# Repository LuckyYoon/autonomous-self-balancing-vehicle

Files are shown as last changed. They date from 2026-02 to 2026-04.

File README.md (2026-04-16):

# Autonomous Self-Balancing Vehicle

This project explores the design and implementation of an autonomous, self-balancing bicycle using a reaction wheel for stabilization. The system combines embedded control, power electronics, and robotic autonomy to achieve balance, perception, and navigation on a dynamically unstable platform.

A reaction wheel driven by a high-speed motor provides roll stabilization, while steering, drive, and braking actuators enable controlled motion. Low-level balancing is handled by an embedded controller, with higher-level perception and autonomy running on an onboard computer using ROS2.

The autonomy stack integrates stereo vision, LiDAR, and inertial sensing to perform visual SLAM, localization, and obstacle-aware navigation. The project emphasizes tight integration between mechanical design, real-time control, and perception-driven decision making.

This repository contains the hardware designs, embedded firmware, autonomy software, and documentation developed in the course of building and testing the system.

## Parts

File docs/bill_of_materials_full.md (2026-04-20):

# Bill of Materials - Full Configuration

| Category | Item | Qty | Notes | Unit Cost | Total Cost |
|---|---|---:|---|---:|---:|
| Bike | [Harper Fixie Bike](https://retrospec.com/products/harper-fixie-bike-single-speed-legacy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) | 1 | This fixed gear bike has a tubular frame making it easier to design mounts. It also reduces any unnecessary parts, for a lightweight bicycle that is easier to balance. | $219.99 | $219.99 |
| Active Reaction Wheel | [Low-Carbon Steel Disc 6" Diameter, 1" Long](https://www.mcmaster.com/7786T74/) | 1 | Steel disk stock for the active reaction wheel. It is 1" thick (motor shaft is 0.787" long), and has a 6" diameter which give us a good weight and inertia for the wheel. | $33.62 | $33.62 |
| Active Reaction Wheel | [ODESC V4.2 24V Single-Drive FOC BLDC Motor Controller](https://www.amazon.com/FLIPSKY-Single-Drive-High-Current-High-Precision-Configuration/dp/B0CB64MVHC/) | 1 | A BLDC motor controller based on the Odrive. Rated for 24V 70A continuous, and is capable of FOC, CAN, hall sensor input, and many other features. | $39.99 | $39.99 |
| Active Reaction Wheel | [2Pcs STM32F411CEU6](https://www.amazon.com/Buying-STM32F411CEU6-Development-Board-Programming/dp/B0DLNDY4V7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) | 1 | STM32F4 Board, which will serve as the active reaction wheel controller. Comes with two boards. | $15.99 | $15.99 |
| Active Reaction Wheel & SLAM Odometry | [ICM45686 Six-Axis Accelerometer Gyroscope Sensor](https://www.ebay.com/itm/227180134829?chn=ps&google_free_listing_action=view_item) | 1 | With a noise of only 3 mdps, and a bias stability of up to 1.5 deg/h this module is considered an incredibly accurate and reliable IMU for its price. | $16.99 | $16.99 |
| Active Reaction Wheel | [M3 Anti-Vibration Standoffs and Rubber Mounts](https://www.amazon.com/Glarks-Anti-Vibration-Standoffs-Controller-Absorption/dp/B0D7C8SVTG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) | 1 | M3 anti-vibration mounts for the IMU. | $13.96 | $13.96 |
| Active Reaction Wheel | [6S Lipo Battery 2200mAh 150C](https://www.amazon.com/OVONIC-Battery-2200mAh-Truggy-Racing/dp/B0D3HSTFSS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) | 1 | 22.2V 6S lipo battery for the active reaction wheel. Having the battery separate from the rest of the system isolates the stabilization and prevents backflow from the wheel to the rest of the bike. This battery can also handle the peak torque current from the reaction wheel. | $34.99 | $34.99 |
| Active Reaction Wheel | [Motor with encoder magnet - M8325s 100KV](https://shop.odriverobotics.com/products/m8325s?variant=44666594328646) | 1 | New motor for the reaction wheel. Peak torque is 6.6 Nm and it can handle much higher current. Please purchase with express shipping. | $188.48 | $188.48 |
| Active Reaction Wheel | [AS5047P Magnetic Encoder](https://www.amazon.com/AS5047P-Magnetic-Position-Breakout-Compatible/dp/B0DLJ6XDNM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) | 1 | Magnetic encoder for the M8325s motor. | $24.99 | $24.99 |
| Electrical | [60 PCS 6 Inches Reusable Cable Ties](https://www.amazon.com/Reusable-Newlan-Adjustable-Organizer-Management/dp/B081HH5X61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) | 1 | Reusable velcro cable ties for cable management. | $6.98 | $6.98 |
| Electrical | [24V 8Ah 30A BMS Lithium Battery with Charger](https://www.amazon.com/hplitebik-Lithium-Ebike-Scooter-Battery/dp/B0DZNRRRZ6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) | 1 | 24V 8Ah should give us plenty of range at low speeds. The maximum discharge of the battery is 750W, which should be enough to handle our power needs. | $74.99 | $74.99 |
| Electrical | [Terminal Block](https://www.amazon.com/Terminal-Positions-Pre-Insulated-Terminals-MILAPEAK/dp/B08ZY6D58J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) | 1 | Comes with three different sets of terminal blocks. Can handle a max of 600V and 25A. | $9.77 | $9.77 |
| Electrical | [DC 24V to 12V 5A Converter 60W](https://www.amazon.com/EPBOWPT-Converter-Regulator-Voltage-Transformer/dp/B0DPZYH3C7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) | 1 | This is a 24V to 12V DC-DC converter for the Jetson Orin Nano. | $9.99 | $9.99 |
| Electrical | [2Pcs Toggle Switch with Cover](https://www.amazon.com/weideer-Position-Aircraft-Terminals-KL-C101-RMZ-DZ/dp/B09XKBRL3V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) | 1 | Two toggle switches for the main and reaction wheel batteries. Can handle up to 30A and has a cover for protection. | $9.99 | $9.99 |
| Steering | [160KG Digital RC Servo 270 Degree 24V](https://www.amazon.com/ANNIMOS-Steering-Waterproof-Quadcopter-Helicopter/dp/B0D6RZCVNJ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) | 1 | 24V 160kg servo for steering with 270 degrees of rotation. | $59.83 | $59.83 |
| Main Drive | [Bidirectional 110A Brushed ESC 12V 24V](https://www.amazon.com/Bidirectional-Electric-Controller-Industrial-Yuenhoang/dp/B09KKMKBWN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) | 1 | Main DC drive motor speed controller. 5V PWM input (will need level shifter for orin) and forward/reverse switching. 40A continuous max current. | $32.99 | $32.99 |
| Main Drive | [25H Chain 480 Links](https://www.amazon.com/KAMIER-Breaker-Electric-Scooter-2-Stroke/dp/B0CKFGB5FG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) | 1 | Chain for the main drive motor. | $18.98 | $18.98 |
| Main Drive | [90T Rear Sprocket](https://cart.electricscooterparts.com/rear-sprocket-for-currie-ezip-izip-gt-mongoose-and-schwinn-electric-scooters) | 1 | Rear sprocket for the main drive system. Will have a 90T/11T gear reduction. | $59.95 | $59.95 |
| SLAM | [Right Angle USB 3.0 Cable](https://www.amazon.com/MTUERANC-Degree-Charging-Tablets-3-3feet/dp/B0DC6M5P5F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) | 1 | Right angle USB 3.0 cable for the ZED2i camera | $8.99 | $8.99 |
| SLAM | [TEAMGROUP MP33 256GB PCIe Gen3x4 M.2 2280 SSD](https://www.amazon.com/TEAMGROUP-MP33-256GB-Gen3x4-TM8FP6256G0C101/dp/B07XHMB5GP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) | 1 | 256GB PCIe Gen3x4 SSD in 2280 form factor for the jetson orin nano. | $70.99 | $70.99 |
| SLAM | [SanDisk 1TB SSD PCIE Gen 3.0, 3,200 MB/s](https://www.amazon.com/SanDisk-1TB-SSD-Plus-NVMe-SDSSDA3N-1T00-G26/dp/B0CN3N3591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) | 1 | 1TB NVMe SSD Gen 3.0 x 4. Uses the full Gen 3.0 x 4 that the Jetson Orin NVMe port is capable of. At double the speed of the other drive, it will work much better for swap (1TB because the speed scales with the storage). | $139.31 | $139.31 |
| SLAM | [NVIDIA Jetson Orin Nano Super Developer Kit](https://www.amazon.com/NVIDIA-Jetson-Orin-Nano-Developer/dp/B0BZJTQ5YP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) | 1 | The NVIDIA Jetson Orin Nano Super Developer Kit. | $245.00 | $245.00 |
| SLAM | [6FT 5.5mm x 2.5mm to Bare Wire DC Power Pigtail Cable](https://www.amazon.com/Pigtail-5-5x2-5mm-Adapter-Surveillance-Security/dp/B09T2ZXY58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) | 1 | DC barrel jack pigtail cable for powering the Orin Nano. | $6.99 | $6.99 |
| SLAM | [Ultra-Small RPi Pinout Terminal Block Breakout Board](https://www.amazon.com/Ultra-Small-Pinout-Terminal-Breakout-Raspberry/dp/B08LH9ZBQ1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) | 1 | GPIO pin breakout board for the Jetson Orin Nano. | $17.99 | $17.99 |
| SLAM | [FHL-LD19 Plus 2D Lidar Sensor](https://www.amazon.com/WayPonDEV-FHL-LD19-Plus-Lidar-Sensor/dp/B0DP4HQ8VB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) | 1 | 2D lidar sensor with 80ft(25m) range and tools for ROS integration. | $99.99 | $99.99 |
| SLAM | [ZED2i Stereo Camera](https://www.stereolabs.com/store/products/zed-2i) | 1 | Stereo depth camera for SLAM. | $499.00 | $499.00 |

**Total:** $1950.73

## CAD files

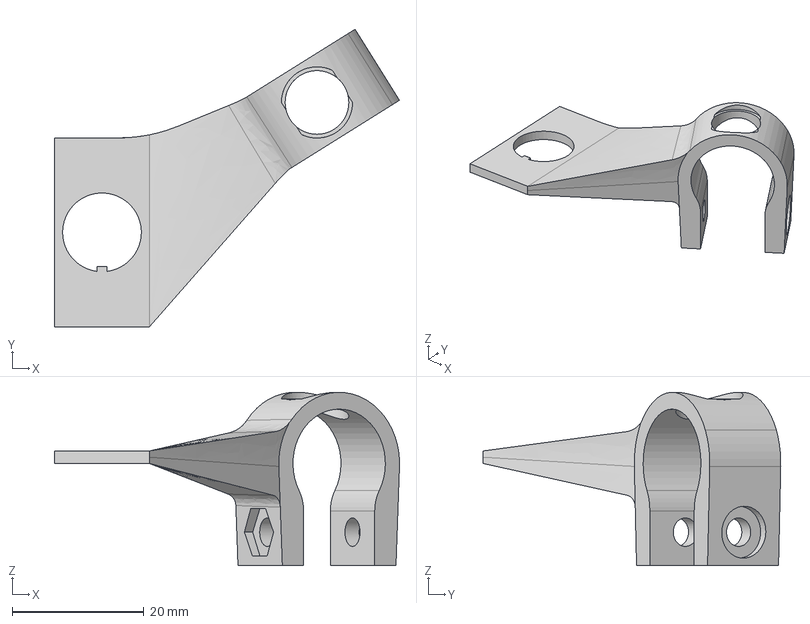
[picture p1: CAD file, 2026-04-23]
docs/CAD/STEP/Switch Mount.step
52.3 x 45.1 x 26.3 mm

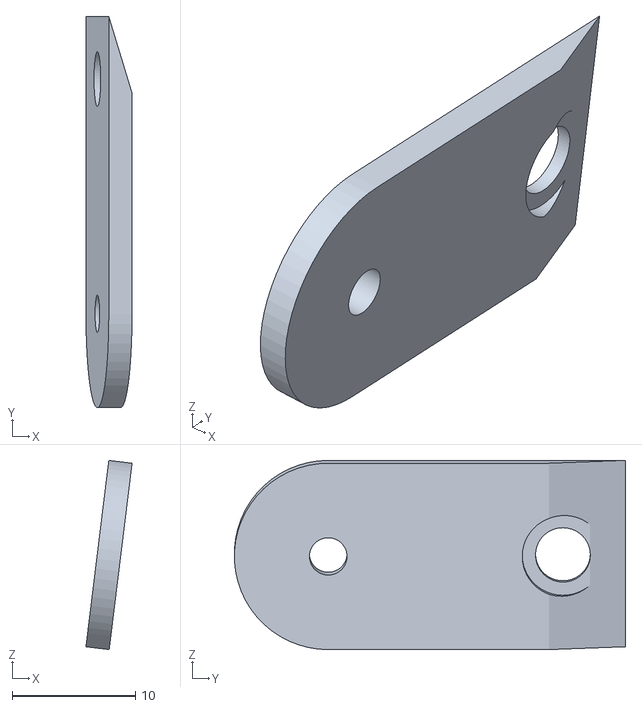
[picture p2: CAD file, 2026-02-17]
docs/CAD/STL/Chain Tensioner Cover.stl
3.75 x 31.7 x 15.4

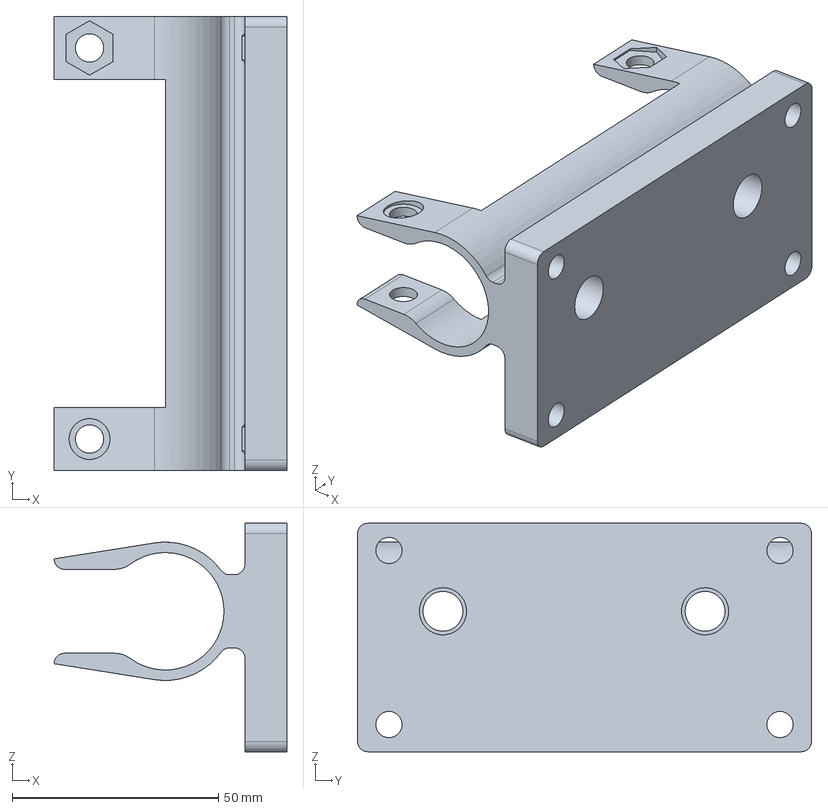
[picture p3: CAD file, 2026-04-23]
docs/CAD/STEP/Drive Motor Mount.step
56.4 x 110.0 x 55.4 mm

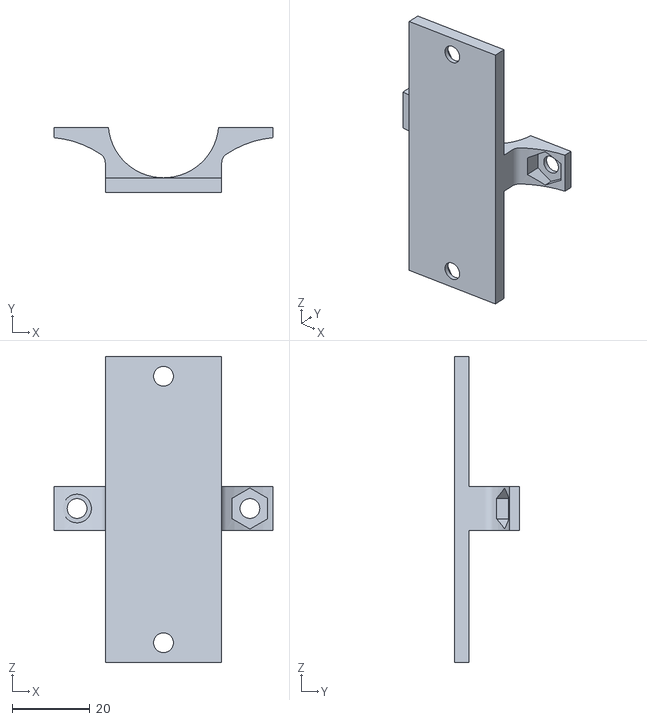
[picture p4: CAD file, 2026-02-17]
docs/CAD/STL/Terminal Mount.stl
56.3 x 16.8 x 78.7

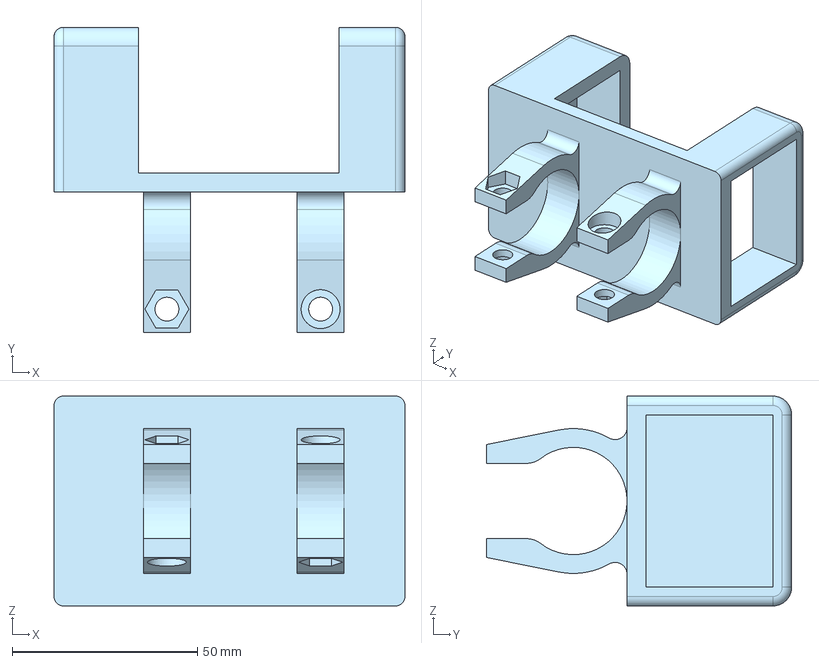
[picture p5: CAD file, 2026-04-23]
docs/CAD/STEP/Flywheel battery motor mount.step
94.7 x 82.4 x 56.6 mm

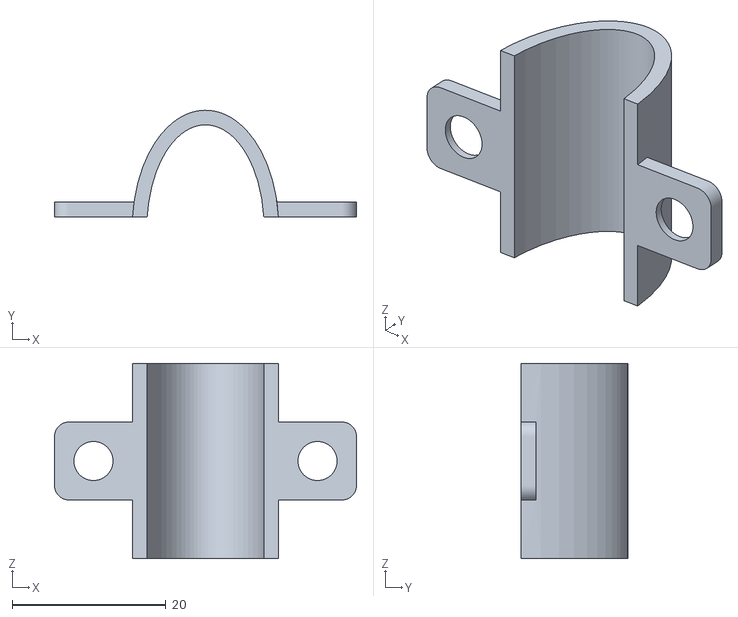
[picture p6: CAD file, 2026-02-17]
docs/CAD/STL/Chain Tensioner Clamp.stl
39.3 x 13.9 x 25.4

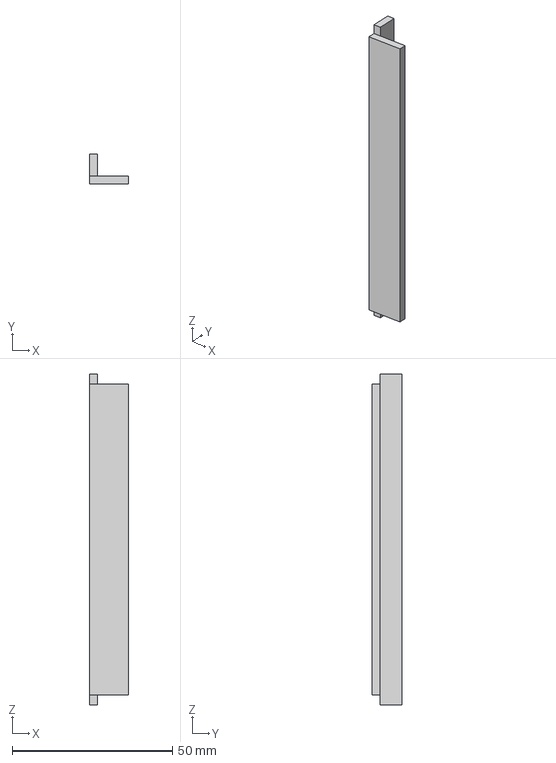
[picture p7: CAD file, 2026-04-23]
docs/CAD/STEP/Electronics Mount - cover.step
12.1 x 9.40 x 103.4 mm

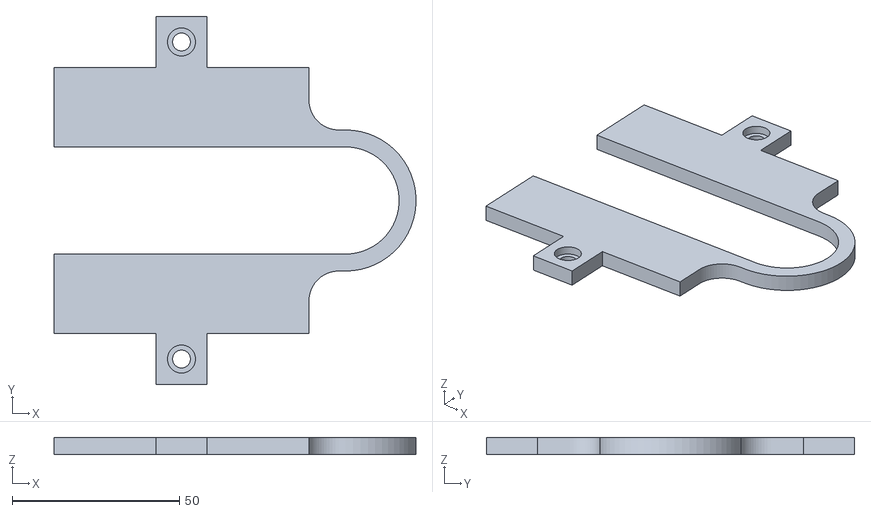
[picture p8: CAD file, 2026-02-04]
docs/CAD/STL/Battery Mount Cover.stl
108.2 x 110.0 x 5.08

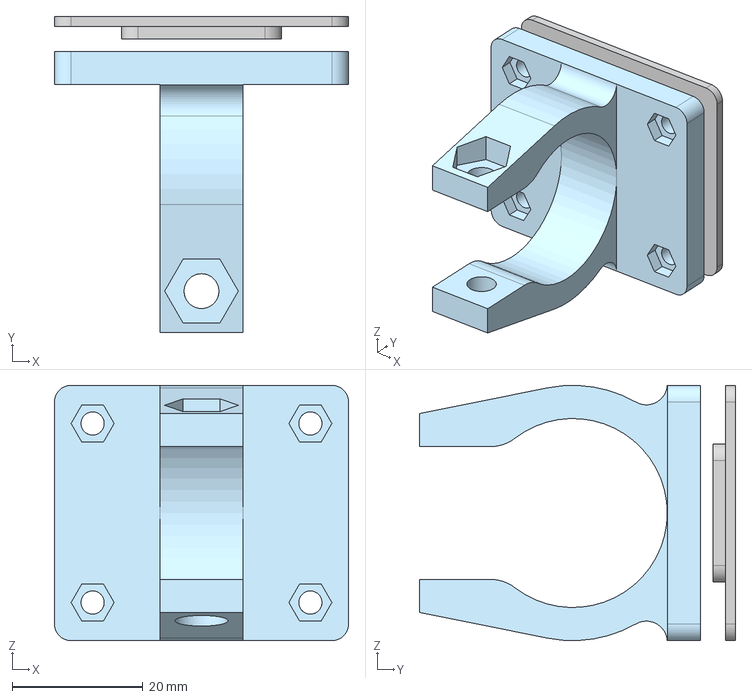
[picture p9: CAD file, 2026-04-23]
docs/CAD/STEP/IMU Mount.step
45.0 x 48.4 x 39.1 mm

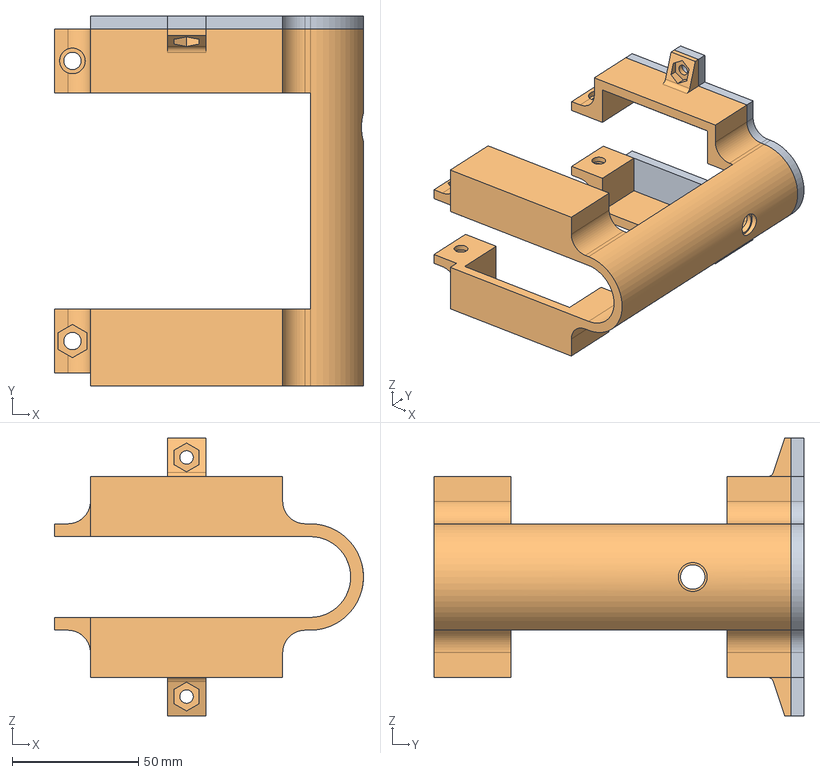
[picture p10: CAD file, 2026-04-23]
docs/CAD/STEP/Battery Mount.step
122.4 x 146.6 x 110.0 mm

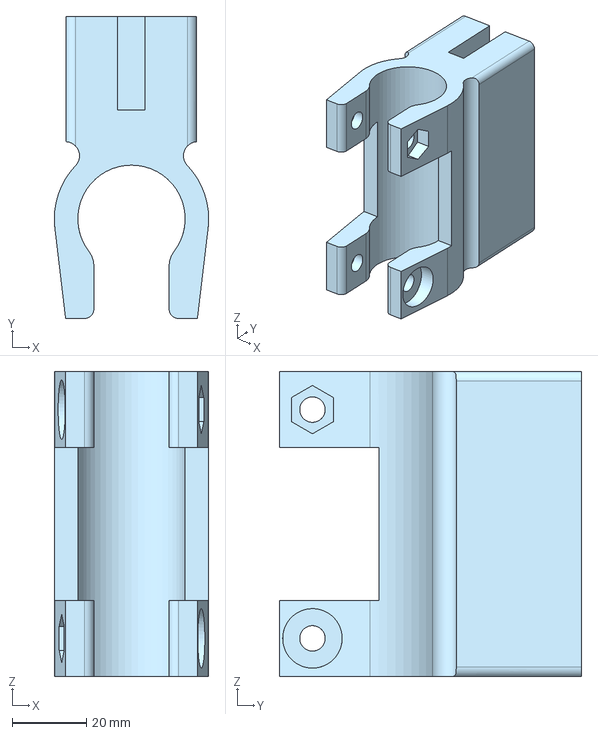
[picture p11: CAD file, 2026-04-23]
docs/CAD/STEP/Servo Mount.step
41.7 x 81.5 x 82.3 mm

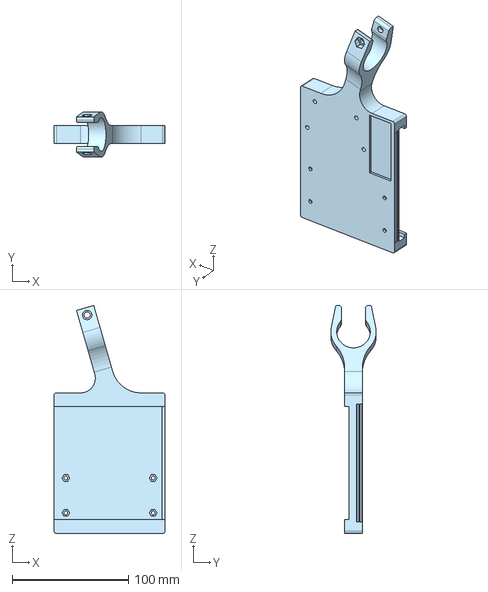
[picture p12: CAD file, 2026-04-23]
docs/CAD/STEP/Electronics Mount.step
95.6 x 39.1 x 196.4 mm

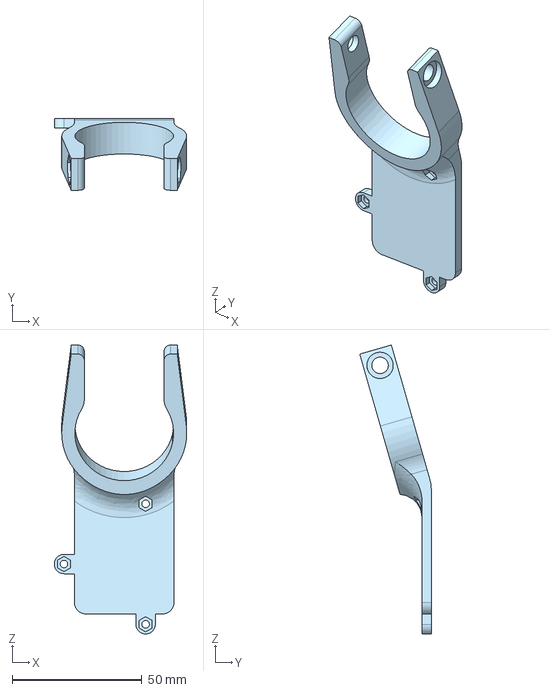
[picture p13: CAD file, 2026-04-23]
docs/CAD/STEP/LiDAR Mount.step
51.1 x 27.6 x 111.5 mm

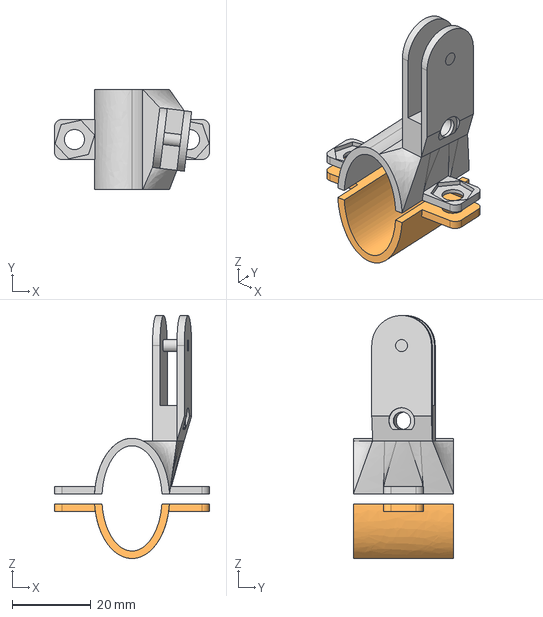
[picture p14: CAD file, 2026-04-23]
docs/CAD/STEP/Chain Tensioner.step
39.3 x 25.4 x 61.6 mm

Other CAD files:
docs/CAD/STL/Battery Mount.stl
docs/CAD/STL/Chain Tensioner.stl
docs/CAD/STL/Servo Mount.stl
docs/CAD/STL/drive_motor_mount.stl

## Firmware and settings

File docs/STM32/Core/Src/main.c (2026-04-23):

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
#include "main.h"
#include "usb_device.h"

/* USER CODE BEGIN Includes */
#include <string.h>
#include <stdio.h>
#include <math.h>
#include <stdlib.h>
#include "usbd_cdc_if.h"

#define CS_LOW()  HAL_GPIO_WritePin(GPIOB, GPIO_PIN_0, GPIO_PIN_RESET)
#define CS_HIGH() HAL_GPIO_WritePin(GPIOB, GPIO_PIN_0, GPIO_PIN_SET)

#define ICM45686_REG_DATA_BASE        0x00
#define ICM45686_REG_PWR_MGMT0        0x10
#define ICM45686_REG_INT1_CONFIG0     0x16
#define ICM45686_REG_INT1_STATUS0     0x19
#define ICM45686_REG_ACCEL_CONFIG0    0x1B
#define ICM45686_REG_GYRO_CONFIG0     0x1C
#define ICM45686_REG_WHO_AM_I         0x72
#define ICM45686_REG_IREG_ADDR_15_8   0x7C
#define ICM45686_REG_IREG_ADDR_7_0    0x7D
#define ICM45686_REG_IREG_DATA        0x7E
#define ICM45686_SREG_CTRL_ADDR_H     0xA2
#define ICM45686_SREG_CTRL_ADDR_L     0x67
#define ICM45686_SREG_DATA_BIG_ENDIAN (1u << 1)
#define ICM45686_WHOAMI_VALUE         0xE9
#define ICM45686_ACCEL_2G_200HZ       0x48
#define ICM45686_GYRO_125DPS_200HZ    0x58
#define ICM45686_PWR_ACCEL_GYRO_LN    0x0F
#define ICM45686_INT1_CFG_EN_DRDY     (1u << 2)
#define ICM45686_INT1_STATUS_DRDY     (1u << 2)

#define ENCODE4(v, sign_c, whole_i, frac_i) do { \
    (sign_c)  = ((v) < 0.0f) ? '-' : '+';         \
    int _m    = (int)(fabsf(v) * 10000.0f);        \
    (whole_i) = _m / 10000;                        \
    (frac_i)  = _m % 10000;                        \
} while (0)

#define USB_RX_BUF_SIZE  128
/* USER CODE END Includes */

SPI_HandleTypeDef hspi1;
TIM_HandleTypeDef htim2;
UART_HandleTypeDef huart1;

/* USER CODE BEGIN PV */
volatile uint8_t  usb_rx_buf[USB_RX_BUF_SIZE];
volatile uint16_t usb_rx_head = 0;
volatile uint16_t usb_rx_tail = 0;

static char       usb_line[64];
static uint8_t    usb_line_idx = 0;
/* USER CODE END PV */

void SystemClock_Config(void);
static void MX_GPIO_Init(void);
static void MX_USART1_UART_Init(void);
static void MX_SPI1_Init(void);
static void MX_TIM2_Init(void);

/* USER CODE BEGIN 0 */

void USB_RxCallback(uint8_t *buf, uint32_t len)
{
    for (uint32_t i = 0; i < len; i++)
    {
        uint16_t next = (usb_rx_head + 1) % USB_RX_BUF_SIZE;
        if (next != usb_rx_tail)
        {
            usb_rx_buf[usb_rx_head] = buf[i];
            usb_rx_head = next;
        }
    }
}

void ODESC_Send(char *cmd)
{
    HAL_UART_Transmit(&huart1, (uint8_t*)cmd, strlen(cmd), 5);
}

void USB_Print(char *msg)
{
    CDC_Transmit_FS((uint8_t*)msg, strlen(msg));
}

void IMU_Write(uint8_t reg, uint8_t data)
{
    uint8_t tx[2] = { reg & 0x7F, data };
    CS_LOW();
    HAL_SPI_Transmit(&hspi1, tx, 2, HAL_MAX_DELAY);
    CS_HIGH();
}

uint8_t IMU_Read(uint8_t reg)
{
    uint8_t tx[2] = { reg | 0x80, 0x00 };
    uint8_t rx[2] = {0};
    CS_LOW();
    HAL_SPI_TransmitReceive(&hspi1, tx, rx, 2, HAL_MAX_DELAY);
    CS_HIGH();
    return rx[1];
}

void IMU_ReadMulti(uint8_t reg, uint8_t *buf, uint8_t len)
{
    uint8_t tx[len + 1];
    uint8_t rx[len + 1];
    tx[0] = reg | 0x80;
    memset(tx + 1, 0x00, len);
    CS_LOW();
    HAL_SPI_TransmitReceive(&hspi1, tx, rx, len + 1, HAL_MAX_DELAY);
    CS_HIGH();
    memcpy(buf, rx + 1, len);
}

void IMU_WriteIREG(uint8_t addr_h, uint8_t addr_l, uint8_t data)
{
    uint8_t tx[4];
    tx[0] = ICM45686_REG_IREG_ADDR_15_8 & 0x7F;
    tx[1] = addr_h;
    tx[2] = addr_l;
    tx[3] = data;
    CS_LOW();
    HAL_SPI_Transmit(&hspi1, tx, 4, HAL_MAX_DELAY);
    CS_HIGH();
    HAL_Delay(1);
}

void IMU_Init(void)
{
    HAL_Delay(10);
    uint8_t who = IMU_Read(ICM45686_REG_WHO_AM_I);
    if (who != ICM45686_WHOAMI_VALUE) return;

    IMU_WriteIREG(ICM45686_SREG_CTRL_ADDR_H,
                  ICM45686_SREG_CTRL_ADDR_L,
                  ICM45686_SREG_DATA_BIG_ENDIAN);

    uint8_t int1_cfg0 = IMU_Read(ICM45686_REG_INT1_CONFIG0);
    int1_cfg0 |= ICM45686_INT1_CFG_EN_DRDY;
    IMU_Write(ICM45686_REG_INT1_CONFIG0, int1_cfg0);

    IMU_Write(ICM45686_REG_ACCEL_CONFIG0, ICM45686_ACCEL_2G_200HZ);
    IMU_Write(ICM45686_REG_GYRO_CONFIG0,  ICM45686_GYRO_125DPS_200HZ);
    IMU_Write(ICM45686_REG_PWR_MGMT0,     ICM45686_PWR_ACCEL_GYRO_LN);

    HAL_Delay(50);
}

#define GYRO_LSB_PER_DPS  262.0f
#define ACCEL_SENS        16384.0f
#define DEG2RAD           0.01745329251f
#define DT                0.005f

#define CF_ALPHA          0.9995f
#define GYRO_LPF_ALPHA    0.1f
#define FALL_LIMIT        0.1f

static float angle       = 0.0f;
static float gy_bias     = 0.0f;
static float gy_filtered = 0.0f;
static float setpoint    = 0.0f;

float Kp = 650.0f;
float Ki = 0.0f;
float Kd = 80.0f;

static float integral = 0.0f;
#define INTEGRAL_LIMIT  1.0f
#define MAX_TORQUE      7.0f

#define OUTER_INTERVAL_TICKS  10
#define SETPOINT_LIMIT        1.0f
#define TORQUE_DEADBAND       0.0f
#define SETPOINT_SLEW_RATE    0.0001f

float K_outer = 0.01f;

static float torque_sum = 0.0f;

#define VBUS_INTERVAL_TICKS   2000
#define VBUS_LOW_THRESHOLD    20.0f
#define BLINK_PERIOD_TICKS    25

static uint8_t  vbus_low   = 0;
static uint32_t blink_tick = 0;

float clamp(float x, float min, float max)
{
    if (x < min) return min;
    if (x > max) return max;
    return x;
}

void IMU_CalibrateGyro(void)
{
    int32_t sum = 0;
    const int samples = 500;
    for (int i = 0; i < samples; i++)
    {
        uint8_t buf[14];
        IMU_ReadMulti(ICM45686_REG_DATA_BASE, buf, 14);
        int16_t gy = (int16_t)((buf[8] << 8) | buf[9]);
        sum += gy;
        HAL_Delay(2);
    }
    gy_bias = (float)sum / samples;
}

void IMU_InitAngle(void)
{
    const int samples = 500;
    float angle_sum = 0.0f;
    for (int i = 0; i < samples; i++)
    {
        uint8_t buf[14];
        IMU_ReadMulti(ICM45686_REG_DATA_BASE, buf, 14);
        int16_t ax_raw = (int16_t)((buf[0] << 8) | buf[1]);
        int16_t az_raw = (int16_t)((buf[4] << 8) | buf[5]);
        float ax_g = ax_raw / ACCEL_SENS;
        float az_g = az_raw / ACCEL_SENS;
        angle_sum += atan2f(ax_g, az_g);
        HAL_Delay(2);
    }
    angle = angle_sum / samples;
}

void ODESC_InitTorqueMode(void)
{
    ODESC_Send("w axis0.controller.config.vel_limit 35\n");   HAL_Delay(10);
    ODESC_Send("w axis0.controller.config.control_mode 1\n"); HAL_Delay(10);
    ODESC_Send("w axis0.controller.config.input_mode 1\n");   HAL_Delay(10);
    ODESC_Send("w axis0.requested_state 8\n");                HAL_Delay(100);
}

float ODESC_GetVBus(void)
{
    uint8_t flush;
    while (HAL_UART_Receive(&huart1, &flush, 1, 1) == HAL_OK);

    ODESC_Send("r vbus_voltage\n");

    char resp[32] = {0};
    uint8_t c;
    uint8_t idx = 0;
    uint32_t deadline = HAL_GetTick() + 10;
    while (HAL_GetTick() < deadline && idx < sizeof(resp) - 1)
    {
        if (HAL_UART_Receive(&huart1, &c, 1, 1) == HAL_OK)
        {
            if (c == '\n') break;
            resp[idx++] = c;
        }
    }
    char *end;
    return strtof(resp, &end);
}

float ODESC_GetFloat(const char *request)
{
    uint8_t flush;
    while (HAL_UART_Receive(&huart1, &flush, 1, 1) == HAL_OK);

    ODESC_Send((char *)request);

    char resp[32] = {0};
    uint8_t c;
    uint8_t idx = 0;
    uint32_t deadline = HAL_GetTick() + 10;
    while (HAL_GetTick() < deadline && idx < sizeof(resp) - 1)
    {
        if (HAL_UART_Receive(&huart1, &c, 1, 1) == HAL_OK)
        {
            if (c == '\n') break;
            resp[idx++] = c;
        }
    }
    char *end;
    float val = strtof(resp, &end);
    return (end != resp) ? val : 0.0f;
}

static float servo_poly_raw(float x)
{
    float x2 = x * x;
    float x3 = x2 * x;
    float x4 = x3 * x;
    return 8.21f
         + (-0.0189f)     * x
         + 1.59e-5f       * x2
         + (-5.79e-9f)    * x3
         + 7.69e-13f      * x4;
}

static float servo_poly_shift = 0.0f;

static void servo_poly_init(void)
{
    servo_poly_shift = servo_poly_raw(1500.0f);
}

static float servo_poly(float x)
{
    return servo_poly_raw(x) - servo_poly_shift;
}

static float servo_signed_offset(uint32_t pw)
{
    float epw = (float)pw + 25.0f;
    if (epw >= 1500.0f)
        return -servo_poly(epw);
    else
        return servo_poly(3000.0f - epw);
}

static uint32_t prev_servo_pw = 1475;

static void set_motor_pwm(uint32_t pw)
{
    if (pw < 775)  pw = 775;
    if (pw > 2175) pw = 2175;
    __HAL_TIM_SET_COMPARE(&htim2, TIM_CHANNEL_2, pw);
}

static void set_servo_pwm(uint32_t pw)
{
    if (pw < 1100) pw = 1100;
    if (pw > 1900) pw = 1900;

    __HAL_TIM_SET_COMPARE(&htim2, TIM_CHANNEL_1, pw);

    if (pw == prev_servo_pw)
        return;

    float delta = servo_signed_offset(pw) - servo_signed_offset(prev_servo_pw);
    setpoint = clamp(setpoint + delta, -SETPOINT_LIMIT, SETPOINT_LIMIT);
    prev_servo_pw = pw;
}

static void process_usb_line(char *line)
{
    if (line[0] == 'M' || line[0] == 'm')
    {
        uint32_t pw = (uint32_t)atoi(line + 1);
        set_motor_pwm(pw);
    }
    else if (line[0] == 'S' || line[0] == 's')
    {
        uint32_t pw = (uint32_t)atoi(line + 1);
        set_servo_pwm(pw);
    }
}

static void poll_usb_rx(void)
{
    while (usb_rx_tail != usb_rx_head)
    {
        uint8_t c = usb_rx_buf[usb_rx_tail];
        usb_rx_tail = (usb_rx_tail + 1) % USB_RX_BUF_SIZE;

        if (c == '\n' || c == '\r')
        {
            if (usb_line_idx > 0)
            {
                usb_line[usb_line_idx] = '\0';
                process_usb_line(usb_line);
                usb_line_idx = 0;
            }
        }
        else if (usb_line_idx < (sizeof(usb_line) - 1))
        {
            usb_line[usb_line_idx++] = (char)c;
        }
    }
}

/* USER CODE END 0 */

int main(void)
{
  HAL_Init();

  SystemClock_Config();

  MX_GPIO_Init();
  MX_USART1_UART_Init();
  MX_USB_DEVICE_Init();
  MX_SPI1_Init();
  MX_TIM2_Init();

  /* USER CODE BEGIN 2 */
  HAL_TIM_PWM_Start(&htim2, TIM_CHANNEL_1);
  HAL_TIM_PWM_Start(&htim2, TIM_CHANNEL_2);

  __HAL_TIM_SET_COMPARE(&htim2, TIM_CHANNEL_1, 1475);
  __HAL_TIM_SET_COMPARE(&htim2, TIM_CHANNEL_2, 1475);

  servo_poly_init();
  IMU_Init();
  IMU_CalibrateGyro();
  IMU_InitAngle();
  ODESC_InitTorqueMode();

  static uint32_t outer_tick = 0;
  static uint32_t vbus_tick  = 0;
  /* USER CODE END 2 */

  /* USER CODE BEGIN WHILE */
  while(1)
  {
        poll_usb_rx();

        uint8_t status = IMU_Read(ICM45686_REG_INT1_STATUS0);
        if (!(status & ICM45686_INT1_STATUS_DRDY))
            continue;

        uint8_t buf[14];
        IMU_ReadMulti(ICM45686_REG_DATA_BASE, buf, 14);

        int16_t ax_raw = (int16_t)((buf[0] << 8) | buf[1]);
        int16_t az_raw = (int16_t)((buf[4] << 8) | buf[5]);
        float ax_g = ax_raw / ACCEL_SENS;
        float az_g = az_raw / ACCEL_SENS;

        int16_t gy_raw = (int16_t)((buf[8] << 8) | buf[9]);
        float gy_dps  = ((float)gy_raw - gy_bias) / GYRO_LSB_PER_DPS;
        float gy_rad  = gy_dps * DEG2RAD;

        gy_filtered = GYRO_LPF_ALPHA * gy_rad + (1.0f - GYRO_LPF_ALPHA) * gy_filtered;

        float accel_angle = atan2f(ax_g, az_g);
        angle = CF_ALPHA * (angle + gy_rad * DT) - (1.0f - CF_ALPHA) * accel_angle;

        if (fabsf(angle) > FALL_LIMIT)
        {
            ODESC_Send("c 0 0.000\n");
            integral    = 0.0f;
            gy_filtered = 0.0f;
            torque_sum  = 0.0f;
            outer_tick  = 0;
            continue;
        }

        float error = setpoint - angle;
        integral = clamp(integral + error * DT, -INTEGRAL_LIMIT, INTEGRAL_LIMIT);
        float output = (Kp * error) + (Ki * integral) - (Kd * gy_filtered);
        output = clamp(output, -MAX_TORQUE, MAX_TORQUE);

        int torque_milli = (int)(output * 1000.0f);
        int torque_abs   = abs(torque_milli);
        char cmd[32];
        if (torque_milli < 0)
            snprintf(cmd, sizeof(cmd), "c 0 -%d.%03d\n",
                     torque_abs / 1000, torque_abs % 1000);
        else
            snprintf(cmd, sizeof(cmd), "c 0 %d.%03d\n",
                     torque_abs / 1000, torque_abs % 1000);
        ODESC_Send(cmd);

        torque_sum += output;
        outer_tick++;
        if (outer_tick >= OUTER_INTERVAL_TICKS)
        {
            float avg_torque = torque_sum / outer_tick;
            torque_sum = 0.0f;
            outer_tick = 0;

            if (fabsf(avg_torque) > TORQUE_DEADBAND)
            {
                float correction = K_outer * avg_torque;
                correction = clamp(correction, -SETPOINT_SLEW_RATE, SETPOINT_SLEW_RATE);
                setpoint  += correction;
                setpoint   = clamp(setpoint, -SETPOINT_LIMIT, SETPOINT_LIMIT);
            }
        }

        vbus_tick++;
        if (vbus_tick >= VBUS_INTERVAL_TICKS)
        {
            vbus_tick = 0;
            float vbus = ODESC_GetVBus();
            vbus_low = (vbus > 0.0f && vbus < VBUS_LOW_THRESHOLD) ? 1 : 0;
        }

        blink_tick++;
        if (!vbus_low)
        {
            HAL_GPIO_WritePin(GPIOC, GPIO_PIN_13, GPIO_PIN_SET);
            blink_tick = 0;
        }
        else if (blink_tick >= BLINK_PERIOD_TICKS)
        {
            blink_tick = 0;
            HAL_GPIO_TogglePin(GPIOC, GPIO_PIN_13);
        }
    /* USER CODE END WHILE */

    /* USER CODE BEGIN 3 */
  }
  /* USER CODE END 3 */
}

void SystemClock_Config(void)
{
  RCC_OscInitTypeDef RCC_OscInitStruct = {0};
  RCC_ClkInitTypeDef RCC_ClkInitStruct = {0};

  __HAL_RCC_PWR_CLK_ENABLE();
  __HAL_PWR_VOLTAGESCALING_CONFIG(PWR_REGULATOR_VOLTAGE_SCALE1);

  RCC_OscInitStruct.OscillatorType = RCC_OSCILLATORTYPE_HSI|RCC_OSCILLATORTYPE_HSE;
  RCC_OscInitStruct.HSEState = RCC_HSE_ON;
  RCC_OscInitStruct.HSIState = RCC_HSI_ON;
  RCC_OscInitStruct.HSICalibrationValue = RCC_HSICALIBRATION_DEFAULT;
  RCC_OscInitStruct.PLL.PLLState = RCC_PLL_ON;
  RCC_OscInitStruct.PLL.PLLSource = RCC_PLLSOURCE_HSE;
  RCC_OscInitStruct.PLL.PLLM = 15;
  RCC_OscInitStruct.PLL.PLLN = 144;
  RCC_OscInitStruct.PLL.PLLP = RCC_PLLP_DIV2;
  RCC_OscInitStruct.PLL.PLLQ = 5;
  if (HAL_RCC_OscConfig(&RCC_OscInitStruct) != HAL_OK)
  {
    Error_Handler();
  }

  RCC_ClkInitStruct.ClockType = RCC_CLOCKTYPE_HCLK|RCC_CLOCKTYPE_SYSCLK
                              |RCC_CLOCKTYPE_PCLK1|RCC_CLOCKTYPE_PCLK2;
  RCC_ClkInitStruct.SYSCLKSource = RCC_SYSCLKSOURCE_HSI;
  RCC_ClkInitStruct.AHBCLKDivider = RCC_SYSCLK_DIV1;
  RCC_ClkInitStruct.APB1CLKDivider = RCC_HCLK_DIV1;
  RCC_ClkInitStruct.APB2CLKDivider = RCC_HCLK_DIV1;

  if (HAL_RCC_ClockConfig(&RCC_ClkInitStruct, FLASH_LATENCY_0) != HAL_OK)
  {
    Error_Handler();
  }
}

static void MX_SPI1_Init(void)
{
  hspi1.Instance = SPI1;
  hspi1.Init.Mode = SPI_MODE_MASTER;
  hspi1.Init.Direction = SPI_DIRECTION_2LINES;
  hspi1.Init.DataSize = SPI_DATASIZE_8BIT;
  hspi1.Init.CLKPolarity = SPI_POLARITY_LOW;
  hspi1.Init.CLKPhase = SPI_PHASE_1EDGE;
  hspi1.Init.NSS = SPI_NSS_SOFT;
  hspi1.Init.BaudRatePrescaler = SPI_BAUDRATEPRESCALER_2;
  hspi1.Init.FirstBit = SPI_FIRSTBIT_MSB;
  hspi1.Init.TIMode = SPI_TIMODE_DISABLE;
  hspi1.Init.CRCCalculation = SPI_CRCCALCULATION_DISABLE;
  hspi1.Init.CRCPolynomial = 10;
  if (HAL_SPI_Init(&hspi1) != HAL_OK)
  {
    Error_Handler();
  }
}

static void MX_TIM2_Init(void)
{
  TIM_ClockConfigTypeDef sClockSourceConfig = {0};
  TIM_MasterConfigTypeDef sMasterConfig = {0};
  TIM_OC_InitTypeDef sConfigOC = {0};

  htim2.Instance = TIM2;
  htim2.Init.Prescaler = 15;
  htim2.Init.CounterMode = TIM_COUNTERMODE_UP;
  htim2.Init.Period = 19999;
  htim2.Init.ClockDivision = TIM_CLOCKDIVISION_DIV1;
  htim2.Init.AutoReloadPreload = TIM_AUTORELOAD_PRELOAD_ENABLE;
  if (HAL_TIM_Base_Init(&htim2) != HAL_OK)
  {
    Error_Handler();
  }
  sClockSourceConfig.ClockSource = TIM_CLOCKSOURCE_INTERNAL;
  if (HAL_TIM_ConfigClockSource(&htim2, &sClockSourceConfig) != HAL_OK)
  {
    Error_Handler();
  }
  if (HAL_TIM_PWM_Init(&htim2) != HAL_OK)
  {
    Error_Handler();
  }
  sMasterConfig.MasterOutputTrigger = TIM_TRGO_RESET;
  sMasterConfig.MasterSlaveMode = TIM_MASTERSLAVEMODE_DISABLE;
  if (HAL_TIMEx_MasterConfigSynchronization(&htim2, &sMasterConfig) != HAL_OK)
  {
    Error_Handler();
  }
  sConfigOC.OCMode = TIM_OCMODE_PWM1;
  sConfigOC.Pulse = 1475;
  sConfigOC.OCPolarity = TIM_OCPOLARITY_HIGH;
  sConfigOC.OCFastMode = TIM_OCFAST_DISABLE;
  if (HAL_TIM_PWM_ConfigChannel(&htim2, &sConfigOC, TIM_CHANNEL_1) != HAL_OK)
  {
    Error_Handler();
  }
  sConfigOC.Pulse = 1475;
  if (HAL_TIM_PWM_ConfigChannel(&htim2, &sConfigOC, TIM_CHANNEL_2) != HAL_OK)
  {
    Error_Handler();
  }
  HAL_TIM_MspPostInit(&htim2);
}

static void MX_USART1_UART_Init(void)
{
  huart1.Instance = USART1;
  huart1.Init.BaudRate = 115200;
  huart1.Init.WordLength = UART_WORDLENGTH_8B;
  huart1.Init.StopBits = UART_STOPBITS_1;
  huart1.Init.Parity = UART_PARITY_NONE;
  huart1.Init.Mode = UART_MODE_TX_RX;
  huart1.Init.HwFlowCtl = UART_HWCONTROL_NONE;
  huart1.Init.OverSampling = UART_OVERSAMPLING_16;
  if (HAL_UART_Init(&huart1) != HAL_OK)
  {
    Error_Handler();
  }
}

static void MX_GPIO_Init(void)
{
  GPIO_InitTypeDef GPIO_InitStruct = {0};

  __HAL_RCC_GPIOC_CLK_ENABLE();
  __HAL_RCC_GPIOH_CLK_ENABLE();
  __HAL_RCC_GPIOA_CLK_ENABLE();
  __HAL_RCC_GPIOB_CLK_ENABLE();

  HAL_GPIO_WritePin(GPIOC, GPIO_PIN_13, GPIO_PIN_RESET);
  HAL_GPIO_WritePin(GPIOB, GPIO_PIN_0, GPIO_PIN_SET);

  GPIO_InitStruct.Pin = GPIO_PIN_13;
  GPIO_InitStruct.Mode = GPIO_MODE_OUTPUT_PP;
  GPIO_InitStruct.Pull = GPIO_NOPULL;
  GPIO_InitStruct.Speed = GPIO_SPEED_FREQ_LOW;
  HAL_GPIO_Init(GPIOC, &GPIO_InitStruct);

  GPIO_InitStruct.Pin = GPIO_PIN_0;
  GPIO_InitStruct.Mode = GPIO_MODE_OUTPUT_PP;
  GPIO_InitStruct.Pull = GPIO_NOPULL;
  GPIO_InitStruct.Speed = GPIO_SPEED_FREQ_LOW;
  HAL_GPIO_Init(GPIOB, &GPIO_InitStruct);
}

void Error_Handler(void)
{
  /* USER CODE BEGIN Error_Handler_Debug */
  __disable_irq();
  while (1)
  {
  }
  /* USER CODE END Error_Handler_Debug */
}

#ifdef USE_FULL_ASSERT
void assert_failed(uint8_t *file, uint32_t line)
{
}
#endif

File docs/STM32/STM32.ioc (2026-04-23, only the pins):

Mcu.UserName=STM32F411CEUx
PA0-WKUP.Signal=S_TIM2_CH1_ETR
PA1.Signal=S_TIM2_CH2
PA10.Signal=USART1_RX
PA11.Signal=USB_OTG_FS_DM
PA12.Signal=USB_OTG_FS_DP
PA5.Signal=SPI1_SCK
PA6.Signal=SPI1_MISO
PA7.Signal=SPI1_MOSI
PA9.Signal=USART1_TX
PB0.Signal=GPIO_Output
PC13-ANTI_TAMP.Signal=GPIO_Output

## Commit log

2026-02-04 Added battery.md, drive-motor.md, and rear-sprocket.md with thumbnail images
2026-02-04 Updated thumbnail image for rear-sprocket.md
2026-02-04 Added cad directory and .stl files. Updated bicycle.md and completed drive-motor.md
    [Battery Mount Cover.stl, Battery Mount.stl, drive_motor_mount.stl]
2026-02-04 Added drive motor test script
2026-02-17 Added .stl files for Chain Tensioner, Terminal Mount, and Servo Mount.
    [Chain Tensioner Clamp.stl, Chain Tensioner Cover.stl, Chain Tensioner.stl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]
2026-02-18 Updated Servo Mount.stl
    [Servo Mount.stl]
2026-04-15 Added STM32 IDE file
2026-04-15 Moved STM32
2026-04-20 Added Bill of Materials
2026-04-23 Add Chain Tensioner CAD
2026-04-23 Adding CAD files
    [Battery Mount.step, Chain Tensioner.step, Drive Motor Mount.step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]
2026-04-23 Rename STL folder
2026-04-23 Updated STM32 files
2026-04-23 Changed repository cad to STL
    [Battery Mount Cover.stl, Battery Mount.step, Battery Mount.stl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]
2026-04-23 Fixed STL
    [Battery Mount.step, Chain Tensioner.step, Drive Motor Mount.step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]
2026-04-23 Deleted old cad directory
    [Battery Mount Cover.stl, Battery Mount.stl, Chain Tensioner Clamp.stl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]
2026-04-23 Added STEP directory and moved all CAD files to CAD directory
    [Battery Mount Cover.stl, Battery Mount.step, Battery Mount.stl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]
2026-04-23 Removed desktop.ini files from STEP and STL

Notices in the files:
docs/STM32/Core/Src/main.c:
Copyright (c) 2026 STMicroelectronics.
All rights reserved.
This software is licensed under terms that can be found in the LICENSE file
